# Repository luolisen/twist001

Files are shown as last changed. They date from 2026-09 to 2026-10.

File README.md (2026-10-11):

# twist001 · 六轴机械臂与具身智能实验

围绕自建六轴机械臂、双指夹爪和双相机开展建模、控制与具身智能实验。当前仓库以 **STM32 六轴固件、ESP32 夹爪固件、REV6 双相机 MuJoCo 仿真**为基础，保留三模型训练归档及机械设计资料。

本页更新至2026-10-10：固件与相机发布沿用2026-10-08记录，补入三模型阶段监督及v2技能研究结果。源码构建、仿真烟测、模型评估和实机验证分别记录，不将它们视为同一项验收。

## 当前模块

| 模块 | 仓库内容 | 状态与入口 |
| --- | --- | --- |
| STM32 六轴控制 | FinalIntegration v3.0，STM32F407VG，X42S CAN、示教/回放、夹爪链路 | 重新编译通过；[构建说明](arm/STM32/README.md) |
| ESP32 夹爪控制 | 配套纯 P 控制、端点减速、反向制动、CAN 节点 7、Wi-Fi/BLE 夹爪接口 | 重新编译通过；[配置与构建](arm/ESP32/README.md) |
| REV6 仿真 | 六轴机械臂、完整夹爪、前置与腕部相机、基础及方块任务场景 | 加载、渲染及短步数数值检查通过；[使用说明](model/RL/README.md) |
| 三模型与技能研究 | v1阶段监督、WM-FK、v2 Skill Router与Transport重力前馈 | 已知场景拿起保持、局部跟踪通过；完整搬运/放置未通过；[实验记录](model/three_model_training/README.md) |
| ROS 2 | 既有节点及已同步的 REV6 MuJoCo 资源 | 当前更新未进行 ROS 2 整链路验收；[集成边界](arm/README.md) |
| 机械资料 | SolidWorks、STEP、打印工程、材料清单及 PCB 资料 | 历史资料，尚未逐项核对与 REV6 的一致性；[机械资料说明](model/README.md) |

## 架构方向与集成状态

当前仿真架构采用**VLA阶段内连续生成动作、WM预测准备执行动作的后果、Jev发放有限且可撤销的阶段许可**。复合抓取抬升阶段覆盖夹爪接续及正常控制交还；每块持续检查公开输入、控制权和原物理保护。Jev拒绝、超时或无效返回不默认放行。

2026-10-10，同一次在线仿真完整执行34块/10880步，在10.880秒完成拿起保持；8.320秒原评价仍失败。完整物理轨迹与VLA加辅助成功基线一致，因此证明阶段监督保住了已知场景能力，尚未证明WM/Jev提升成功率、安全性或泛化。详见[实际结果与源码](model/three_model_training/experiments/skill_supervision_20261010/README.md)。

v2已实现Pick/Hold/Transport/Place/Recovery技能接口，局部固定结构重力前馈使末端跟踪误差由3.202mm降至0.196mm。最新长路径只取得70mm静态合法前缀，尚未物理执行；公开持物确认、自动Transport交接、Place松爪与完整抓放仍未通过。

```mermaid
flowchart TD
    Task[任务目标] --> Jev[Jev：阶段许可、拒绝与重规划]
    Obs[公开双相机、编码器与回执] --> VLA[SmolVLA：阶段内连续动作]
    Obs --> WM[World Model：未来响应与风险]
    VLA --> WM
    WM --> Jev
    Jev --> Gate[有限许可与控制所有权]
    VLA --> Gate
    Gate --> Protect[原限位、物理保护与执行回执]
    Protect --> Sim[已知MuJoCo场景拿起保持通过]
    Gate -. 技能交接仍待验证 .-> Skills[v2 Transport / Place]
    Protect -. 尚未联合验收 .-> STM[STM32六轴与ESP32夹爪]
```

本地 FinalIntegration 工程另有 `host/alan_robot` 主机控制层与独立 ROS 桥接包，**尚未纳入本仓库此次发布**。仓库中的既有 ROS 2 节点不能直接等同于这套新执行层。固件源码中已有配套 CAN 协议；新固件尚未烧录或完成实机联合验证。

## 快速开始：REV6 双相机仿真

从仓库根目录执行，使用独立 Python 环境：

```bash
python -m venv .venv
source .venv/bin/activate
python -m pip install -r model/RL/requirements.txt

# 基础机械臂与相机场景
python model/RL/src/demo.py

# 方块与放置目标场景
python model/RL/src/demo.py --scene task

# 离屏渲染两路图像并进行 100 步数值检查
python model/RL/src/demo.py --check /tmp/rev6-camera-check
```

上述环境激活命令适用于 macOS/Linux。macOS 打开交互窗口时，将 `python` 换为环境中的 `mjpython`；离屏检查使用普通 Python。

### 当前相机版本

| 相机 | 垂直视角 | 仿真原始图像 | 策略图像 | 处理方式 |
| --- | --- | --- | --- | --- |
| 前置 `front_rgb` | 48° | 640×360 | 256×256 | 完整视野缩为 256×144，上下各补 56 像素 |
| 腕部 `wrist_camera` | 45.2° | 640×360 | 512×512 | 完整视野缩为 512×288，上下各补 112 像素 |

该版本基于 REV6 Camera45.2，并加入实拍参考的前置相机姿态对齐。保留完整 16:9 视野，不以中心裁剪替代；逐设备内参、畸变与实机全运动可见性仍待验证。

模型来源、原始及发布文件指纹见 [provenance.json](model/RL/provenance.json)，相机合同见 [camera_contract.json](model/RL/camera_contract.json)。基础场景的桌板为视觉几何，任务场景的桌板有碰撞几何。旧独立 PPO 入口已被当前仿真包替换。

## 固件构建

### STM32F407VG

准备 ARM GNU 工具链和 CMake，在仓库根目录执行：

```bash
cmake -S arm/STM32/Control_Code -B /tmp/twist001-stm32-build \
  -DCMAKE_TOOLCHAIN_FILE="$PWD/arm/STM32/Control_Code/cmake/arm-gcc.cmake"
cmake --build /tmp/twist001-stm32-build -j4
```

工具链目录可通过 `STM32_ARM_TOOLCHAIN` 指定，详见 [STM32 文档](arm/STM32/README.md)。

### ESP32 夹爪

准备 Arduino CLI 和 esp32 core 3.3.11，在仓库根目录执行：

```bash
python3 arm/ESP32/tools/provision_wireless.py
arduino-cli compile --fqbn esp32:esp32:esp32doit-devkit-v1 \
  --build-property build.partitions=huge_app \
  --build-property upload.maximum_size=3145728 \
  --build-path /tmp/twist001-esp32-build arm/ESP32/ESP32_Final
```

配置工具为新环境生成本机密钥，并保留已有配置；私有配置不提交。固件使用 `huge_app` 3 MB 分区，无 OTA。以上命令只构建、不烧录，配置及客户端配套要求见 [ESP32 文档](arm/ESP32/README.md)。

## 已完成的验证与剩余工作

2026-10-08 的仓库更新验证包括：

- STM32 重新编译通过：FLASH 24,940 B、RAM 6,464 B。
- ESP32 重新编译通过：应用 1,710,674 B、全局 RAM 72,524 B，使用临时测试配置。
- 六组固件回归通过，覆盖协议、应用、CAN 分片、夹爪权限/租约及轨迹限速，并启用 ASan/UBSan。
- REV6 基础及任务场景在 MuJoCo 3.13.0 下通过加载、双相机渲染与各 100 步数值烟测。
- ROS MuJoCo 资源一致性及单项模型契约检查通过；未进行当前 ROS 工作空间的构建或运行验收。

可核对的记录见 [联合验证](arm/firmware_tools/verification.md) 和 [固件源码指纹](arm/firmware_tools/source_manifest.json)。这些固件与渲染检查不证明抓取、放置、碰撞或三模型任务成功率。WM19仍保留历史失败门槛；最新三模型闭环和局部控制结果单独归档，不追溯改写旧结果。

新固件烧录、六轴方向/传动比/参考位与限位标定、无线实机通信、相机校准、跨场景可靠性、完整抓放和实机模型闭环仍需分别完成。真实夹爪最大行程为 **74.63 mm**，仿真为 **80 mm**，模型动作接入时必须显式处理量程差异。

## 主要目录

以下仅列出当前工程入口及参考资料，不是仓库全部文件清单。

```text
twist001/
├── arm/
│   ├── STM32/Control_Code/       # 六轴与夹爪 CAN 链路固件
│   ├── ESP32/ESP32_Final/        # 配套夹爪固件
│   ├── ESP32/tools/              # 本机无线配置生成
│   ├── firmware_tools/          # 回归脚本、来源指纹与验证记录
│   └── ROS2/src/                # 既有 ROS 节点与 REV6 MuJoCo 资源
└── model/
    ├── RL/                      # REV6 场景、网格、渲染与相机合同
    ├── three_model_training/    # 三模型阶段监督、v2技能研究及WM19历史
    ├── 3D/                      # 历史机械设计与加工资料
    └── 机械臂材料清单.xlsx
```

仓库不提供训练权重、完整数据集、私有仿真状态、设备密钥或固件二进制。旧子目录说明中的历史路径与验证结论，应结合本页所述的当前集成范围使用。

## 许可证

仓库提供 [Apache License 2.0](LICENSE)。第三方驱动、SDK、模型和素材按各自附带的许可证或授权说明使用。

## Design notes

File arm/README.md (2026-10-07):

# 六轴与夹爪控制工程

当前主要入口是配套的 **STM32 六轴固件、ESP32 夹爪固件**及联合验证资料。

| 目录 | 内容 | 说明 |
| --- | --- | --- |
| [STM32](STM32/README.md) | FinalIntegration v3.0 六轴 CAN、示教/回放、夹爪链路 | STM32F407VG；重新编译通过 |
| [ESP32](ESP32/README.md) | 纯 P 夹爪控制、CAN 节点 7、Wi-Fi/BLE 接口 | 重新编译通过；无设备密钥及二进制 |
| [firmware_tools](firmware_tools/verification.md) | 六组回归、源码指纹及验证记录 | 软件验证，不等于实机验收 |
| [ROS2](ROS2/readme.md) | 既有 ROS 2 节点及资源 | 子目录说明包含历史配置，尚需适配当前执行链 |

## 控制分工

STM32 负责六轴电机控制以及与 ESP32 的夹爪 CAN 通信。ESP32 执行夹爪控制，并提供 Wi-Fi/BLE 夹爪查询和指令接口；当前并未实现 ESP32 脱离电脑转发六轴指令或直接连接手柄的 HID 驱动。

本地 FinalIntegration 的 `host/alan_robot` 和独立 ROS 桥接包尚未上传到此次仓库版本。它们负责模型量程适配、参考确认、标定/使能及动作时效门控等工作，不能用仓库现存的旧 ROS 节点代替其集成验收。

## 仿真与 ROS 2 边界

`ROS2/src/arm_asset/` 的 MuJoCo 资源已与 [REV6 双相机仿真](../model/RL/README.md)同步。前置相机为 48°，腕部为 45.2°。

- 当前 `mujoco_sim` 仍提供六关节控制与反馈话题，尚未接入夹爪控制和双相机图像话题。
- `arm_asset/urdf/` 是旧六轴描述，为原控制和标定模块保留；不是当前 REV6 完整夹爪和相机 URDF。
- 部分既有节点和启动文件仍使用旧路径、资源与接口配置。当前更新只完成静态资源和单项模型契约检查，未执行 ROS 2 整链路验证。

先运行仓库根目录说明中的独立仿真；ROS 接入需要另行核对模型、坐标、消息及执行网关。

## 硬件与验证状态

新固件未烧录，未进行最终版实机运动或联合闭环验收。六轴参考位、方向、传动比、限位及相机校准仍需独立验证。真实夹爪行程 0–74.63 mm，仿真为 0–80 mm，不能直接等同。

`STM32/` 下的 PCB 工程及原理图是保留的历史资料，本次没有核对其与 FinalIntegration 接线的一致性。最新软件检查结果见 [联合验证记录](firmware_tools/verification.md)。

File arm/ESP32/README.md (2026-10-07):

# ESP32 FinalIntegration v3.0 夹爪固件

配套 `arm/STM32/Control_Code/`。保留纯 P 控制、力矩保持、端点减速及反向制动；CAN 节点 7，另提供 Wi-Fi TCP 和 BLE GATT 夹爪接口，采用 HMAC、序号、租约、来源独占与有界队列。上电不自动张开。

硬件最大开口 **74.63 mm**，仿真为 **80 mm**，不能直接把两个量程混同。尚未完成无线实机及整臂闭环验收。ESP32 不提供无电脑的六轴 CAN 转发或手柄 HID 直连。

## 构建

安装 Arduino CLI 和 esp32 core 3.3.11。在仓库根目录生成本机独立配置；脚本保留已存在密钥，不打印密钥：

```sh
python3 arm/ESP32/tools/provision_wireless.py
arduino-cli compile --fqbn esp32:esp32:esp32doit-devkit-v1 --build-property build.partitions=huge_app --build-property upload.maximum_size=3145728 --build-path /tmp/twist001-esp32-build arm/ESP32/ESP32_Final
```

固件使用 esp32 core 提供的 Arduino、TWAI、Wire、Wi-Fi、BLE 与 mbedTLS 接口。配置在 `config/private/wireless.json`，生成的 `ESP32_Final/private_config.h` 不提交。配套客户端必须另行配置同一密钥；此次不发布原设备密钥或含密钥二进制。
使用 huge_app 3 MB 分区、无 OTA。此次只构建、不烧录；未来升级必须使用匹配分区表及启动文件。

本次 ESP32 发布源码与 FinalIntegration 原源文件逐字节相同，来源清单及联合验证见 `arm/firmware_tools/`。

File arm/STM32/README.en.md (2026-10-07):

# STM32 firmware

The current firmware is FinalIntegration v3.0 for STM32F407VG. See [current build and validation instructions](README.md). Historical PCB files are unchanged. No flashing or hardware validation was performed.

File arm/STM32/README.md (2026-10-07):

# STM32 FinalIntegration v3.0

当前 `Control_Code/` 全量替换为配套 ESP32 夹爪的 STM32F407VG 最终集成源码：六轴 X42S CAN 控制、示教/回放、有界同步命令、停止保持、夹爪 CAN 查询与控制。六轴回放期间允许夹爪链路，不自动归零。

在仓库根目录构建（只生成固件，不烧录）：

```sh
cmake -S arm/STM32/Control_Code -B /tmp/twist001-stm32-build -DCMAKE_TOOLCHAIN_FILE="$PWD/arm/STM32/Control_Code/cmake/arm-gcc.cmake"
cmake --build /tmp/twist001-stm32-build -j4
```

工具链可通过 `STM32_ARM_TOOLCHAIN` 指向包含 `bin/arm-none-eabi-gcc` 的目录。硬件为 STM32F407VG；链接脚本为 `STM32F407VG_FLASH.ld`。配套夹爪源码见 `arm/ESP32/`；联合回归见 `arm/firmware_tools/test_firmware.sh`。

当前源代码来自独立 FinalIntegration 工程，文件 SHA-256 见 `arm/firmware_tools/source_manifest.json`。`Control_Code/README.md` 与 `manifest.json` 是继承的原工程资料，路径和基线信息不代表当前发布验收；以本页和联合验证记录为准。
原 `jlc.epro2` 与 PCB/原理图图片原样保留，未在本次更新中核验硬件设计一致性。未烧录，未执行实机运动。完整主机网关与 ROS 桥接不在此次固件发布范围内。

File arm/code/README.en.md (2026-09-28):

# Local ASR and Qwen3.5 Testbed

**中文（默认）:** [README.md](README.md)

> **Module Maintainer**: [@LN-101](https://github.com/LN-101) (Responsible for AI CLI entrypoints, model benchmarks, voice/web launchers, and testing harness)

Run all commands from the repository root with `qwen35_env`:

```bash
./qwen35_env/bin/python Code/test.py --list-devices
./qwen35_env/bin/python Code/test.py inventory
./qwen35_env/bin/python Code/voice_stack.py plan
```

## Text Generation Smoke Tests

Qwen3.5 2B and 9B are detected as VLM-style OpenVINO GenAI models, so the
testbed uses `VLMPipeline` automatically.

```bash
./qwen35_env/bin/python Code/test.py generate \
  --model qwen35-2b \
  --device CPU \
  --prompt "Answer in one short sentence: what can you do for a robot safety assistant?" \
  --max-new-tokens 12

./qwen35_env/bin/python Code/test.py generate \
  --model qwen35-9b \
  --device CPU \
  --prompt "Answer in one short sentence: what is your role?" \
  --max-new-tokens 8
```

Device fallback is enabled by default when a requested accelerator fails:

```bash
./qwen35_env/bin/python Code/test.py generate --model qwen35-2b --device NPU --max-new-tokens 6
./qwen35_env/bin/python Code/test.py generate --model qwen35-2b --device GPU --max-new-tokens 6
```

For the current Qwen3.5 2B GPU tuning notes, use the benchmark harness below
with the target OpenVINO device and record the resulting `PerfMetrics` values.

The Qwen3.5 benchmark harness records official generated-token throughput,
TPOT, TTFT, stream chunk cadence, and a hardware telemetry snapshot:

```bash
./qwen35_env/bin/python Code/qwen35_benchmark.py --model qwen35-2b --device GPU
```

Use `official_tokens_per_second` / `mean_official_tokens_per_second` as the
model throughput metric. `stream_chunks_per_second` is only a streaming
smoothness diagnostic.

## ASR Smoke Tests

The Whisper path accepts normalized 16 kHz audio. The built-in WAV loader is
dependency-light and supports PCM WAV files only.

```bash
./qwen35_env/bin/python Code/test.py asr --load-only --device CPU --model whisper-large-v3-turbo
./qwen35_env/bin/python Code/test.py asr --device CPU --audio-sample /path/to/sample_16k.wav --language en
```

If no audio sample is provided, the ASR command validates the model path and
prints the required sample format.

## Safety Assistant Scaffold

The initial project scaffold validates local model assets and a JSON safety-rule
file. The rule store is intentionally owned by code, not by direct model file
writes.

```bash
./qwen35_env/bin/python Code/assistant.py status
```

The modular voice stack entrypoint is:

```bash
./qwen35_env/bin/python Code/voice_stack.py plan
./qwen35_env/bin/python Code/voice_stack.py text-turn --text "请说明机械臂急停规则" --skip-tts
./qwen35_env/bin/python Code/voice_stack.py audio-file --audio /path/to/sample_16k.wav --language zh --skip-tts
./qwen35_env/bin/python Code/voice_stack.py tts --text "机械臂已停止，请确认安全区域。"
```

The default TTS engine remains MeloTTS. A faster optional Piper Huayan backend
is available for listening tests; its default pause setting is the tuned
`--piper-silence-scale 1.0` candidate:

```bash
./qwen35_env/bin/python Code/voice_stack.py tts \
  --tts-engine piper \
  --piper-model-dir .trellis/tasks/05-28-compare-natural-chinese-tts-models/piper_speaches_huayan_model \
  --piper-espeak-data-dir .trellis/tasks/05-28-compare-natural-chinese-tts-models/sherpa_kokoro_model/kokoro-int8-multi-lang-v1_1/espeak-ng-data \
  --text "机械臂已停止，请保持安全距离，确认防护门关闭后再复位。"
```

The latest blind listening pack is under
`.trellis/tasks/05-28-compare-natural-chinese-tts-models/listening_eval/tuned_piper10_vs_melo/`.
Keep Piper optional until that pack wins the listening check. The current
rhasspy model card lists the HuaYan dataset URL as missing and the license as
unknown, so production use also needs an explicit license-risk acceptance or a
replacement voice with clear licensing.

ASR transcripts are normalized before routing. Install OpenCC in `qwen35_env`
so Traditional Chinese Whisper output is converted to Simplified Chinese before
rule/tool intent detection:

```bash
./qwen35_env/bin/python -m pip install opencc-python-reimplemented
```

No-wake realtime microphone listening uses an optional `sounddevice` runtime
dependency. It captures 16 kHz mono microphone audio, segments one utterance at
a time with an energy threshold, then runs the same ASR -> LLM -> ROS2 path:

```bash
sudo apt install portaudio19-dev
./qwen35_env/bin/python -m pip install sounddevice
./qwen35_env/bin/python Code/voice_stack.py listen --no-wake --language zh --skip-tts --dry-run-ros2
```

Useful tuning options are `--speech-threshold`, `--trailing-silence-seconds`,
`--min-speech-seconds`, `--max-utterance-seconds`, `--mic-device`, and
`--max-turns`. Use `--no-ros2` when you only want local ASR/Qwen output during
microphone tuning.

The ROS2 bridge commands run the same voice turn and publish ROS2 topic
messages. Use `--dry-run-ros2` first to inspect the planned messages without
requiring `rclpy`:

```bash
./qwen35_env/bin/python Code/voice_stack.py ros2-text-turn --text "请立即急停机械臂" --skip-tts --dry-run-ros2
./qwen35_env/bin/python Code/voice_stack.py ros2-audio-file --audio /path/to/sample_16k.wav --language zh --skip-tts --dry-run-ros2
```

## Mobile Web UI

The hotspot web surface is a separate entrypoint:

```bash
./qwen35_env/bin/python Code/web_ui.py
```

For the HTTPS phone UI launcher:

```bash
./scripts/start_web_no_ros.sh
```

For real ROS2 Web debugging, build/source the ROS2 workspace, start the default
arm launch, and start the Web UI without `--dry-run-ros2` through:

```bash
./scripts/start_web_with_ros.sh
```

The default launch is `ros2 launch main arm.launch.py`; its default real-robot
path does not start MuJoCo simulation or the K230 camera node. Override the
target with `--ros-launch-package <pkg>` and `--ros-launch-file <file>` or the
matching `AI_OV_ROS2_LAUNCH_PACKAGE` / `AI_OV_ROS2_LAUNCH_FILE` environment
variables. Use `--skip-ros-build` when the ROS2 workspace is already built.
The default build runs plain `colcon build` inside the ROS2 workspace and lets
the ROS build/launch processes inherit that workspace's Python dependency
resolution; it does not force `--symlink-install` or prepend system
`dist-packages`.

Both Web launchers keep Web/ASR at effective nice `0` by default, and the MOSS
TTS child inherits that priority. Set `AI_OV_VOICE_NICE` to an unprivileged
value from `0` through `19` to override it. Vision inference runs at nice `10`
by default; set `AI_OV_MIN_DIS_NICE` in the same range to override it. Negative,
invalid, or unattainable values fail before Web or ROS processes start. The
real ROS launcher leaves arm control, arm state, and emergency-stop aggregation
at nice `0`; only `min_dis` is demoted.

MOSS streaming playback buffers `0.48` seconds of PCM before it starts. After
an underrun it waits for `0.64` seconds of PCM before resuming, giving playback
a larger fixed recovery reserve while retaining the low initial latency now
that YOLO no longer competes for the CPU. Set
`AI_OV_MOSS_PCM_BUFFER_SECONDS=2`, `3`, or `4` to opt back into a larger initial
reserve when comparing latency and continuity under contention.
The default Web stream sends `voice=Xiaoyu` without a prompt WAV, so the ONNX
runtime uses its built-in prompt codes and avoids encoding `zh_11.wav` for each
turn. An explicit `--moss-prompt-audio <wav>` or
`--moss-use-yangmi-prompt-audio` setting still selects reference-audio cloning.
Starting a new Web text or voice turn now stops local playback and waits for the
previous backend/MOSS stream to cancel before the new request begins. The ONNX
worker keeps exclusive ownership of the shared runtime until it exits and its
codec streaming state is reset. If cancellation logs `runtime restart
required` or `/health` reports `runtime_manager.runtime_healthy=false`, restart
the MOSS/Web launcher instead of retrying concurrent turns in the same server.
MOSS affinity is disabled by default; use
`AI_OV_MOSS_CPUS=<cpu-list>` only for explicit affinity experiments. These
settings do not change Web,
ASR, arm control, emergency-stop, or the existing `min_dis` E-core affinity.

If another terminal already owns the full ROS2 graph, attach only the Web UI
without starting duplicate arm/camera nodes:

```bash
./scripts/start_web_with_ros.sh --no-ros-launch
```

The real ROS launcher rejects `--dry-run-ros2`; use `scripts/start_web_no_ros.sh` for
safe UI-only testing.

Before starting the Orbbec/Gemini vision snapshot service as a normal user,
install the udev rules shipped with the ROS2 environment's `pyorbbecsdk`.
Gemini 336 enumerates as `2bc5:0803`; without this rule it can appear in
`lsusb` while the Orbbec SDK still fails with `Access denied` /
`usbEnumerator openUsbDevice failed`:

```bash
sudo sh "$AI_OV_ROS2_WORKSPACE/.venv/lib/python3.12/site-packages/pyorbbecsdk/shared/install_udev_rules.sh"
```

After installing the rule, unplug and replug the camera before starting the
vision service.

To also build and start the ROS2 RGB snapshot service used by visual-analysis
requests:

```bash
./scripts/start_web_no_ros.sh --with-vision-service
```

The launcher still passes `--dry-run-ros2` to the Web UI by default, so robot
command publishing remains disabled while `/vision/capture_snapshot` is
available for VLM snapshots. The service is provided by the ROS2 `camera`
package's `min_dis` node, which also owns the Orbbec RGB/depth pipeline and
minimum-distance context. Use `--vision-service-name <name>` or
`--vision-output-dir <dir>` to override the `min_dis` vision parameters. Use
`--vision-show-window` only when the OpenCV preview windows are wanted.

Do not use `--with-vision-service` if a full ROS2 launch such as
`ros2 launch main arm.launch.py` is already running `min_dis`; two
camera nodes can compete for the same Orbbec device.

It serves a mobile-first local UI with `admin / 12345` login by default,
text chat, browser voice upload, playback of generated TTS audio, and an
emergency-stop button. The first MVP intentionally excludes image upload and
full autonomous arm-agent control.

For real ROS2 publishing, source ROS2 and the workspace first. By default,
emergency-stop voice commands publish JSON requests to `/safety/estop/request`;
use `--direct-estop-topic` only when publishing `std_msgs/Bool` directly to
`/emergency_stop` is desired. The same emergency-stop and release commands also
write the configured arm runtime JSON (`--arm-rules`, default
`Code/config/arm_rules.json`) by setting `arm_stop` / `arm_recover`.

When the Web UI runs without `--dry-run-ros2`, it also subscribes to
`/safety/estop/request` and turns active external stop events (for example the
visual person-distance stop published by the `min_dis` node with
`source=min_distance_camera`) into a browser emergency alert: pending Web work
is canceled, an emergency popup shows the source/reason/distance/threshold, and
a pre-generated alert audio file is played directly with a browser `Audio`
element (never realtime TTS). Provide the audio file at
`local_safety_assistant/web/assets/emergency_alert.wav` with the fixed message
`警告！检测到不安全情况，已经急停`, or replace it with
`--emergency-alert-audio <path>`; it is served at `/emergency-alert-audio`.
The `min_dis` stop is latched after its first unsafe distance. Safe or missing
detections do not release it automatically. A confirmed release asks the camera
to reset, but the camera clears only after either three consecutive valid frames
at least `0.05m` above the configured stop distance or five seconds of valid
camera frames with no person detected. Person reappearance, camera frame loss,
or stale evidence cancels the no-person eligibility; otherwise the stop remains
active.
Synthetic events can be injected through the authenticated
`POST /api/estop/external` route using the same multi-source JSON contract
(`source`, `active`, `latch`, `reason`, plus optional `distance_m`,
`trigger_distance_m`, `threshold_m`, and `release_distance_m`). Camera alerts
show the first unsafe trigger distance, latest person-to-arm distance, and
release gate separately. Dismissing the popup never releases the real emergency stop;
release remains owned by the ROS2 stop-source logic.

The example rule file is:

```text
Code/config/safety_rules.example.json
```

Current-rule questions such as `当前安全规则是什么` are read through the
validated rule tool path, not from prompt memory. Each voice turn first asks
the 2B model for a bounded JSON route: final spoken reply, `load_rules`, or
`edit_rules`. The legacy keyword detector is only a fallback when the route is
invalid. The model may request rule reads with a structured JSON tool envelope
such as `{"type":"tool_call","name":"load_rules","arguments":{}}`; the legacy
`TOOL:load_rules` marker remains a fallback. The default example now
covers personnel intrusion, unknown objects, guard doors, light curtains, ROS
controller alarms, and teach-mode speed limits. After the JSON document is
loaded, Qwen is prompted to understand the rule fields and answer in natural
Chinese: broad questions should summarize every enabled rule briefly without
appending a follow-up suggestion tail, while specific questions should explain only the
matching JSON rule. `Code/voice_stack.py` and `Code/batch_voice_safety.py` both
default to this file and accept `--rules` to point at another validated JSON
rule document.

Rule-edit turns no longer construct a default 9B rule editor. The router should
select `edit_rules` for natural edit requests such as `调整人员安全距离到 1.2 米`;
the patch stage then produces a constrained patch against an existing rule, and
project code applies that patch through validated atomic writes. The checked-in
runtime default is `two-pass` while the MVP is being compared; use
`--rule-edit-strategy one-pass` or `--rule-edit-strategy two-pass` on
`Code/voice_stack.py text-turn --skip-tts` to compare both patch-generation
paths before choosing long-term policy.

Explicit vision requests such as `调用视觉，分析下当前工作环境` route through a
bounded `analyze_environment_vision` tool. The assistant calls a configurable
ROS2 `std_srvs/Trigger` snapshot service, defaulting to
`/vision/capture_snapshot`; on success the Trigger `message` must be JSON with
an `image_path` field and optional `stamp` / `frame_id` metadata:

```json
{"image_path": "/tmp/current_rgb_snapshot.jpg", "stamp": "2026-06-09T12:00:00", "frame_id": "camera_color"}
```

The first implementation is RGB-only. The assistant validates and copies the
snapshot into the authenticated Web runtime image directory, runs Qwen3.5 VLM
analysis, returns a concise Chinese safety summary, and renders the captured
image in the Web chat message. Depth metadata and colorized depth images are
reserved for a later iteration.

If the RGB camera is already published as `sensor_msgs/Image`, the included
snapshot provider node can expose that Trigger service:

```bash
source /opt/ros/<distro>/setup.bash
./qwen35_env/bin/python Code/vision_snapshot_node.py \
  --image-topic /camera/color/image_raw \
  --service-name /vision/capture_snapshot
```

The node accepts common RGB image encodings (`rgb8`, `bgr8`, `rgba8`, `bgra8`,
and `mono8`) and writes JPEG snapshots under `.runtime/vision_snapshots/`.

## Optional Downloads

The testbed is offline once model directories exist. Use the downloader only
to fetch or refresh model assets:

```bash
./qwen35_env/bin/python Code/download.py qwen35-2b
./qwen35_env/bin/python Code/download.py qwen35-9b
./qwen35_env/bin/python Code/download.py asr-whisper-large-v3
./qwen35_env/bin/python Code/download.py asr-whisper-large-v3-turbo
```

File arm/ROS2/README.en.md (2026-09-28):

# ROS 2 Arm Workspace

**中文（默认）:** [readme.md](readme.md)

This directory is the authoritative ROS 2 workspace for the integrated
`nl-industrial-arm-safety` monorepo. It contains the packages that connect the
natural-language AI layer to the camera, arm controller, simulation, and
operator GUI.

> **Module Maintainer**: [@nanshanbot](https://github.com/nanshanbot) (Responsible for ROS 2 node architecture, arm kinematics control, camera RGB-D distance safety & vision snapshots, multi-source e-stop arbitration, MuJoCo simulation & PyQt5 GUI)

## Packages

| Package | Responsibility |
| --- | --- |
| `camera` | Orbbec RGB/depth input, person/arm distance estimation, camera emergency-stop source, and vision snapshot Trigger service |
| `control` | IK, DRL, hand-eye calibration, and control helpers |
| `main` | Launch files, arm state machine, serial feedback, and emergency-stop aggregation |
| `arm_asset` | URDF/MJCF robot description and meshes |
| `mujoco_sim` | MuJoCo simulation node |
| `arm_gui` | PyQt5 ROS 2 status and manual stop interface |

## Build

From the monorepo root:

```bash
source /opt/ros/jazzy/setup.bash
cd ros2
colcon build
source install/setup.bash
```

Generated `build/`, `install/`, `log/`, and `.runtime/` directories are local
state and are intentionally ignored.

## Launch

The integrated launcher normally starts the default arm path from the
repository root:

```bash
./scripts/start_web_with_ros.sh
```

To launch the ROS graph directly:

```bash
source /opt/ros/jazzy/setup.bash
source /path/to/nl-industrial-arm-safety/ros2/install/setup.bash
ros2 launch main arm.launch.py
```

The default real-robot launch does not start MuJoCo simulation or the K230
camera node. Inspect the launch files before selecting simulation or hardware
paths on a new machine.

```bash
ros2 topic pub /goal geometry_msgs/msg/Point "{x: 0.08, y: 0.25, z: 0.2}" --once
```

## Vision Context Snapshot

`camera.min_dis` exposes an AI_ov-compatible Trigger service while keeping the
existing minimum-distance topics unchanged.

Run the camera node:

```bash
source /opt/ros/<distro>/setup.bash
source /path/to/nl-industrial-arm-safety/ros2/install/setup.bash
ros2 run camera min_dis --ros-args \
  -p vision_service_name:=/vision/capture_snapshot \
  -p vision_output_dir:=/path/to/nl-industrial-arm-safety/ros2/.runtime/vision_snapshots
```

Call the service:

```bash
ros2 service call /vision/capture_snapshot std_srvs/srv/Trigger {}
```

On success, `message` is JSON with:

```json
{
  "image_path": "/path/to/nl-industrial-arm-safety/ros2/.runtime/vision_snapshots/vision_context_123.jpg",
  "stamp": "2026-07-05T10:00:00.000Z",
  "frame_id": "camera_frame",
  "min_distance_m": 0.42,
  "human_closest_point": {"x": 0.1, "y": 0.2, "z": 0.7},
  "arm_closest_point": {"x": 0.3, "y": 0.2, "z": 0.6},
  "emergency_stop": false,
  "fresh": true,
  "age_ms": 12.3,
  "source": "min_dis"
}
```

If no completed frame analysis is available, or the cached frame/context is
older than `vision_max_age_ms` (default `1000`), the service returns
`success=false` with a short human-readable error. The image extension parameter
accepts `jpg`, `jpeg`, or `png`.

Use Git branches or patches for team handoff. Do not copy a zip over this
workspace; stage teammate code elsewhere, review the diff, then merge selected
changes.

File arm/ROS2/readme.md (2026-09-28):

# `ros2/` ROS 2 工作空间

**English:** [README.en.md](README.en.md)

这是 `nl-industrial-arm-safety` 的权威 ROS 2 工作空间，负责把自然语言安全助手连接到相机、机械臂控制器、仿真器和操作员 GUI。构建产物 `build/`、`install/`、`log/` 和 `.runtime/` 只在本机生成，不提交到 Git。

> **模块维护者**：[@nanshanbot](https://github.com/nanshanbot)（负责 ROS 2 节点架构、机械臂运动学控制、相机 RGB-D 距离安全与视觉快照、多来源急停仲裁、MuJoCo 仿真及 PyQt5 GUI）

## 包结构

| 包 | 主要文件/节点 | 职责 |
| --- | --- | --- |
| `camera` | `camera/min_dis.py`、`distance_estop.py`、`pose_distance.py` | Orbbec RGB-D、YOLO/OpenVINO 人体/机械臂距离、相机急停和视觉上下文 |
| `control` | `control/ik_control.py`、`drl_control.py` | 逆运动学、DRL 策略、关节控制和手眼参数读取 |
| `main` | `launch/*.launch.py`、`main/arm_state.py` | 启动图、串口协议、工作空间边界、抓放状态机和安全规则同步 |
| `main` | `main/estop_aggregator.py` | 聚合语音、相机、反馈和手动急停来源 |
| `arm_asset` | `urdf/`、`mjcf/`、`meshes/` | 机械臂模型、碰撞/视觉网格和 MuJoCo 资源 |
| `mujoco_sim` | `mujoco_sim/mujoco_sim.py` | `/goal`、`/control`、手眼控制和关节状态的 MuJoCo 仿真 |
| `arm_gui` | `arm_gui/gui_node.py`、`main_window.py` | 状态显示、目标/关节命令和手动急停界面 |

## 关键文件

```text
ros2/
├── colcon_defaults.yaml       colcon 默认构建选项
├── src/
│   ├── arm_asset/             URDF、MJCF、STL 网格和展示图片
│   ├── camera/                相机、距离安全和视觉快照
│   ├── control/               IK、DRL、手眼和策略资源
│   ├── main/                  真实机械臂启动图、状态机和急停仲裁
│   ├── mujoco_sim/            仿真节点和仿真测试
│   └── arm_gui/               PyQt5 ROS 2 GUI
└── readme.md                  本中文说明
```

相机包中随源码保留的二进制 SDK/模型资源可能有独立许可证，重新分发前必须核查来源和条款。

## 构建

在仓库根目录执行：

```bash
source /opt/ros/jazzy/setup.bash
cd ros2
colcon build
source install/setup.bash
```

如果使用外部 ROS 2 工作空间，根目录启动脚本支持：

```bash
AI_OV_ROS2_WORKSPACE=/path/to/ros2 ./scripts/start_web_with_ros.sh
```

默认启动脚本会优先使用仓库内的 `./ros2`，并在真实启动前拒绝存在未提交的 ROS 2 源码/配置变更。仅在明确的本地实验中使用 `AI_OV_ALLOW_DIRTY_ROS=1`。

## 启动图

### 默认真实机械臂路径

```bash
source /opt/ros/jazzy/setup.bash
source install/setup.bash
ros2 launch main arm.launch.py
```

根目录的完整入口会先构建/加载工作空间，再启动 Web UI：

```bash
cd ..
./scripts/start_web_with_ros.sh
```

`main/launch/arm.launch.py` 默认连接：

```text
control/ik_control
        |
main/arm_state -------- main/estop_aggregator
        |
camera/min_dis -------- /emergency_stop
```

默认图不会自动启动 MuJoCo 或 K230 节点。真实硬件启动前，应先审查 launch 参数、串口设备、模型路径、相机状态和急停链路。

### 其他 launch 文件

| 文件 | 用途 |
| --- | --- |
| `arm.launch.py` | 默认控制、状态、相机和急停图 |
| `arm_ik_real.launch.py` | 更直接的真实机械臂 IK 路径 |
| `arm_ik_sim.launch.py` | IK + MuJoCo 仿真路径 |
| `arm_drl_sim.launch.py` | DRL 控制 + MuJoCo 仿真路径 |
| `handeye_calibration.launch.py` | 手眼标定维护图，默认不启用运动 |

仿真/标定都不是生产真实机械臂默认路径。请先阅读对应 launch 文件和节点参数，再在目标设备执行。

## 主要 ROS 2 接口

| 接口 | 类型 | 发布/订阅方 | 作用 |
| --- | --- | --- | --- |
| `/goal` | `geometry_msgs/Point` | AI 桥接、GUI、`arm_state`/仿真 | 目标笛卡尔坐标 |
| `/control` | `sensor_msgs/JointState` | 控制器、GUI、仿真 | 六关节控制目标 |
| `/robot_joint_state` | `sensor_msgs/JointState` | `arm_state` | 真实机械臂反馈 |
| `/mujoco_joint_state` | `sensor_msgs/JointState` | `mujoco_sim`、GUI | 仿真关节反馈 |
| `/min_distance` | `std_msgs/Float32` | `camera/min_dis`、GUI | 人/臂最小距离 |
| `/safety/estop/request` | `std_msgs/String` | 语音/相机、`estop_aggregator` | 带来源和原因的急停请求 JSON |
| `/emergency_stop` | `std_msgs/Bool` | 急停聚合器、控制器、GUI | 有效急停状态 |
| `/voice/transcript` | `std_msgs/String` | AI 桥接 | 语音转写文本 |
| `/voice/assistant_response` | `std_msgs/String` | AI 桥接 | 助手回答 |
| `/vision/capture_snapshot` | `std_srvs/srv/Trigger` | `camera/min_dis` | 获取带时间戳的视觉快照上下文 |

视觉快照调用示例：

```bash
ros2 service call /vision/capture_snapshot std_srvs/srv/Trigger '{}'
```

服务成功时，`message` 为 JSON，包含图片路径、时间戳、帧 ID、最小距离、最近点、急停状态、帧新鲜度和来源。

## 相机安全节点

`camera/min_dis.py` 负责：

- 读取 Orbbec RGB-D 数据；
- 使用 YOLO/OpenVINO 姿态模型识别人和机械臂关键点；
- 在深度无效时使用受限的历史/候选恢复策略；
- 发布 `/min_distance` 和视觉上下文；
- 通过 `/safety/estop/request` 请求锁存相机急停。

默认启动图会把视觉推理限制到指定 CPU、线程数和 `nice`/CPUWeight 范围，以避免语音播放被视觉推理饿死。相机故障、帧过期或距离未知不能被解释为“工作空间安全”。

## 控制与急停

`control/ik_control.py` 从 URDF 读取运动链，进行目标姿态/工作空间/关节限制检查，并将关节目标交给控制接口。`main/arm_state.py` 负责串口反馈、抓放状态机、工作空间边界和控制器通信；它还会拒绝过期、越界或急停状态下的命令。

`main/estop_aggregator.py` 将多个来源合并为一个有效状态：

```json
{"source":"voice_assistant","active":true,"latch":true,"reason":"用户请求急停"}
```

只允许对应来源按规则释放锁存；清除某一个来源不能覆盖其他仍然激活的来源。物理急停和下位机安全链路仍然是最终保护措施。

## 仿真与 GUI

MuJoCo 节点加载 `arm_asset/mjcf/arm_mjcf.xml`，订阅 `/goal` 和 `/control`，发布 `/mujoco_joint_state`，并对关节目标做速度限制。GUI 节点提供目标点、六关节控制、状态订阅和手动 `/emergency_stop`。

这些路径需要桌面显示、MuJoCo/PyQt5 和完整 ROS 2 Python 依赖：

```bash
source /opt/ros/jazzy/setup.bash
source install/setup.bash
ros2 launch main arm_ik_sim.launch.py
```

## 测试

```bash
source /opt/ros/jazzy/setup.bash
cd ros2
colcon test --event-handlers console_direct+
```

当前工作空间可以成功 `colcon build`。`colcon test` 中仍有既存的风格/文档检查失败和少量机械臂状态标定/时序断言差异；这些结果不代表真实硬件安全验收。

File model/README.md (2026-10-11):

# 机械设计与 REV6 仿真

当前独立仿真入口是 [REV6 双相机仿真](RL/README.md)，包括完整夹爪、腕部相机、前置相机以及任务场景。旧 PPO 脚本及独立仿真目录中的旧 URDF 已从当前版本替换；历史内容仍可从 Git 历史查看。

- [仿真启动、依赖及相机合同](RL/README.md)
- [模型来源与文件指纹](RL/provenance.json)
- [三模型阶段监督与技能研究](three_model_training/README.md)
- [历史机械设计资料](3D/) 与 [材料清单](机械臂材料清单.xlsx)：本次未更新，不代表已与 REV6 一致。

相机是实拍对齐候选，完整光学校准与实机运动验证未完成。模型加载及渲染验证不代表任务成功率或碰撞安全验收。

2026-10-10研究记录已补入：已知场景拿起保持及局部重力前馈跟踪通过；完整Transport/Place、公开自主交接和实机仍未通过。源码与精简证据见[研究归档](three_model_training/experiments/skill_supervision_20261010/README.md)。

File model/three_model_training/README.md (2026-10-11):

# 三模型监督、技能研究与历史训练记录

当前仿真分工是VLA负责阶段内连续动作，WM负责动作条件化的未来响应与风险预测，Jev负责有界阶段许可、拒绝、异常处理与重规划。阶段授权通过真实执行门生效，原物理保护独立优先。

- [2026-10-10阶段监督与v2技能研究](experiments/skill_supervision_20261010/README.md)：已知场景10.880秒拿起保持通过，8.320秒未通过；局部Transport前馈跟踪通过，长路径只到静态检查阶段。
- [WM19八候选训练历史](experiments/wm19/README.md)：保留原训练与完整性结果，其独立物理可靠性门槛仍未通过。

当前没有完整三色分拣、自动抓放、公开自主持物确认、实机或实时闭环通过证据。v1与原动作辅助基线轨迹相同，不据此宣称监督收益。v2确定性Transport/Place仍需独立交接、路径、支撑与释放验证，不加载未验证的新Place模型冒充能力。

本目录发布源码快照、精简记录和静态名义指令；不提供神经权重、完整训练集、私有integration_state、设备密钥或固件二进制。离线复核入口不运行模型或物理。研究运行器仍依赖原登记资产与显式有限授权，不能由归档状态自动启动实机。

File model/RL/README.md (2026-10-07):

# REV6 双相机仿真

当前版本完整替换旧独立仿真目录，包含 REV6 机械臂、联动双指夹爪、腕部相机及对齐后的前置相机。
默认 `src/model/mjcf/arm_mjcf.xml` 是相机对齐场景；`task_scene.xml` 是同相机版本的方块与放置目标任务场景。

| 相机 | 视角 | 原始渲染 | 策略图像 | 内容与补边 |
| --- | --- | --- | --- | --- |
| front_rgb | 48° | 640×360 | 256×256 | 256×144，上下各 56 |
| wrist_camera | 45.2° | 640×360 | 512×512 | 512×288，上下各 112 |

保持完整 16:9 视野，不用中心裁剪。前置相机世界位置为 (0.3665, 0.029, 0.355) m；机械臂绕 (0.08, 0.08, 0) 旋转 −90°。相机姿态来自实拍人工对齐，尚未完成逐设备内参、畸变及全运动可见性验收。

## 使用

在仓库根目录安装依赖并运行：

```sh
python -m pip install -r model/RL/requirements.txt
python model/RL/src/demo.py
python model/RL/src/demo.py --scene task
python model/RL/src/demo.py --check /tmp/rev6-camera-check
```

macOS 打开交互窗口使用环境中的 `mjpython model/RL/src/demo.py`。离屏检查使用普通 Python。
仿真启动姿态 J1–J6 为 [0, −0.05, 0.1, 0, 0, 0] rad；控制接口为六个关节目标加夹爪开度（米，0–0.08）。这不是实机上电零位。

## 来源和验证边界

基体来源 `ARM_REV6_CAMERA45P2_MUJOCO`，SHA-256 为 `49cc167d19aba3cf02702e98f1f95e64fabc3dab05aa267ec67d476d4028c7eb`。
相机对齐场景源 SHA-256 为 `986230eea6327b3e1f6a4b470eb44d1582c53c0ac463c3670da4547319da9bc8`；任务场景源为 `02defa53b8d934771f32aed1d0b767bd1a6a820715d5fc0a7eaffa46189cf9ce`。
打包仅修改资源相对路径及 XML 序列化；几何、相机和动力学没有改动，发布文件的新 hash 见 `provenance.json`。

旧六轴 PPO 的 arm.py/test.py 与旧 URDF 副本不纳入本目录；它们不适配当前夹爪、相机和任务接口。三模型历史训练记录保留在 `model/three_model_training/`。
本目录不含数据集、训练权重或自动训练入口。模型加载、图像渲染及短步数烟测不等于抓取成功、碰撞验收、策略可靠性或实机验证。默认对齐场景的桌板是视觉几何；任务场景的桌板有碰撞几何。未合入静态碰撞修复候选。

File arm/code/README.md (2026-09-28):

# `Code/` 命令入口与测试

**English:** [README.en.md](README.en.md)

`Code/` 是仓库根目录下的开发者入口层。这里的 Python 文件大多是兼容性包装器、模型测试命令或批处理工具；核心安全逻辑位于 [`local_safety_assistant/`](../local_safety_assistant/)。

> **模块维护者**：[@LN-101](https://github.com/LN-101)（负责 AI 兼容入口、模型评测、语音与 Web 启动脚本及测试工具链）

## 文件职责

| 路径 | 作用 |
| --- | --- |
| `test.py` | 设备、模型、文本生成和 ASR 冒烟测试入口，实际调用 `local_safety_assistant.model_testbed` |
| `voice_stack.py` | 语音栈 CLI 入口，实际调用 `local_safety_assistant.stack.cli` |
| `web_ui.py` | 移动端 Web UI 入口，实际调用 `local_safety_assistant.web.server` |
| `download.py` | 从 Hugging Face 下载模型到被忽略的 `models/` |
| `piper_tts.py` | Piper TTS 的外部运行器适配 |
| `qwen35_benchmark.py` | Qwen/OpenVINO 生成吞吐和设备遥测基准 |
| `asr_benchmark.py` | Whisper ASR 性能测试辅助 |
| `batch_voice_safety.py` | 批量语音安全回归任务 |
| `assistant.py` | 早期本地助手兼容入口 |
| `vision_snapshot_node.py` | 视觉快照兼容入口；ROS 2 集成实现位于 `ros2/src/camera/` |
| `config/` | 安全规则、机械臂规则和对象标号映射示例 |
| `runtime/` | 不含凭据的运行时配置样例 |
| `tests/` | Python 单元测试和启动脚本契约测试 |

不要直接从模型输出写入 `Code/config/`。规则和对象映射必须通过核心包中的校验与确认流程更新。

## 环境

从仓库根目录执行命令。项目默认使用 `qwen35_env`，也可以把下面命令中的解释器替换成自己的 Python 3.12 环境。

```bash
PY=./qwen35_env/bin/python
$PY -m unittest discover -s Code/tests
$PY -m py_compile Code/*.py local_safety_assistant/stack/*.py local_safety_assistant/web/*.py
```

模型、虚拟环境、缓存和运行时输出不在 Git 中。模型下载前请阅读模型卡和许可证。

## 设备与模型检查

```bash
$PY Code/test.py --list-devices
$PY Code/test.py inventory
$PY Code/voice_stack.py plan
$PY Code/voice_stack.py audio-devices
```

`plan` 输出 ASR、LLM、视觉和 TTS 的 OpenVINO 设备选择；没有对应模型或硬件时，检查命令会明确报告缺失状态。

下载模型到被忽略的 `models/` 目录：

```bash
$PY Code/download.py qwen35-2b
$PY Code/download.py asr-whisper-large-v3-turbo
```

可用别名以 `Code/download.py --help` 和源码中的 `MODEL_REPOS` 为准。需要 Hugging Face 权限时，在本机设置 `HF_TOKEN`，不要把令牌写入命令历史或仓库。

## 文字、音频和语音栈

### 文字回合

先使用 dry-run，确认不会发布真实 ROS 2 命令：

```bash
$PY Code/voice_stack.py text-turn \
  --text "请说明机械臂急停规则" \
  --skip-tts \
  --dry-run-ros2
```

常用参数包括 `--llm-model`、`--asr-model`、`--rules`、`--object-mapping`、`--arm-rules` 和 `--max-new-tokens`。

### 音频文件

输入必须是可读取的 PCM WAV，推荐单声道、16 kHz：

```bash
$PY Code/voice_stack.py audio-file \
  --audio /path/to/sample_16k.wav \
  --language zh \
  --skip-tts \
  --dry-run-ros2
```

### 麦克风

```bash
$PY Code/voice_stack.py listen \
  --language zh \
  --max-turns 1 \
  --no-ros2
```

调试麦克风时先使用 `--no-ros2`；`--speech-threshold`、`--trailing-silence-seconds`、`--mic-device` 和 `--max-utterance-seconds` 用于调整端点检测。

### TTS

```bash
$PY Code/voice_stack.py tts \
  --text "机械臂已进入安全状态" \
  --tts-engine melo
```

支持 `moss`、`melo` 和 `piper` 三种适配器。运行时、模型和厂商/第三方依赖需要在本机单独安装；本仓库不提供一键安装脚本。

## ROS 2 桥接

语音栈默认只生成计划；启用 ROS 2 桥接后，完成的回合会按确定性规则发布：

```bash
$PY Code/voice_stack.py ros2-text-turn \
  --text "请立即急停机械臂" \
  --skip-tts \
  --dry-run-ros2
```

去掉 `--dry-run-ros2` 才会尝试连接 ROS 2。桥接使用的默认话题为：

| 话题 | 类型 | 用途 |
| --- | --- | --- |
| `/voice/transcript` | `std_msgs/String` | 规范化后的输入文本 |
| `/voice/assistant_response` | `std_msgs/String` | 助手回答 |
| `/safety/estop/request` | `std_msgs/String` | 带来源和原因的急停请求 |
| `/emergency_stop` | `std_msgs/Bool` | 直接急停状态 |
| `/goal` | `geometry_msgs/Point` | 经过解析的目标坐标 |

规则查询、规则编辑、对象映射和抓取意图不会被当成普通坐标命令直接发布；它们必须经过对应的确认/解析流程。

## Web UI

从仓库根目录使用启动脚本：

```bash
./scripts/start_web_no_ros.sh
```

这个模式默认使用 `--dry-run-ros2`，适合界面、ASR、LLM 和 TTS 联调。完整 ROS 2 集成使用：

```bash
./scripts/start_web_with_ros.sh
```

详细环境变量包括 `AI_OV_PYTHON`、`AI_OV_WEB_HOST`、`AI_OV_WEB_PORT`、`AI_OV_WEB_ADMIN_PASSWORD`、`AI_OV_TTS_ENGINE` 和 `AI_OV_ROS2_WORKSPACE`。Web 默认凭据只适合本地开发，部署前必须更改。

## 配置文件

- `config/safety_rules.example.json`：规则文档示例，包含版本、规则条件和动作；
- `config/arm_rules.json`：机械臂急停、恢复、减速等运行时规则；
- `config/object_mapping.example.json`：A/B/C/D 对象标号示例；
- `runtime/voice_stack.example.json`：不含秘密的语音栈参数样例。

修改规则时，核心包会检查 JSON 类型、重复 ID、已知业务字段、距离范围和不可修改字段，并使用临时文件加原子替换写回。

## 测试范围

```bash
$PY -m unittest discover -s Code/tests
$PY -m py_compile Code/*.py local_safety_assistant/stack/*.py local_safety_assistant/web/*.py scripts/*.py
bash -n scripts/start_web_no_ros.sh scripts/start_web_with_ros.sh
```

测试不代表真实机械臂安全认证。涉及 ROS 2、相机、串口、模型和 TTS 的集成行为必须在目标设备上另外验收。

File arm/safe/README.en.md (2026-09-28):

# `local_safety_assistant/` Local Safety Assistant Core

**中文（默认）:** [README.md](README.md)

This is the project's core Python package. It integrates local ASR, LLM/VLM, TTS, vision context, and the Web UI, while strictly bounding model outputs within verifiable rules, confirmation lifecycles, and deterministic ROS 2 message boundaries.

> **Module Maintainer**: [@LN-101](https://github.com/LN-101) (Responsible for AI core architecture, OpenVINO inference, Whisper/MeloTTS speech pipeline, safety rule engine, Web UI, and ROS 2 message bridge)

## Processing Pipeline

```text
Text / Audio Input
    |
    +--> stack/asr.py -------- Whisper ASR
    |
    +--> stack/pipeline.py --- Intent normalization, rule tools, LLM response
    |          |
    |          +-------------- rules.py / arm_rules.py
    |          +-------------- object_mapping.py
    |          +-------------- workspace_snapshot.py
    |
    +--> stack/tts.py -------- Melo / MOSS / Piper TTS
    |
    +--> stack/ros2_bridge.py  Deterministic ROS 2 message plan or publish
    |
    +--> web/service.py ------ Web session, confirmations, emergency stop, streaming audio
```

## Files and Modules

| Path | Responsibility |
| --- | --- |
| `app.py` | `status` command; checks OpenVINO devices, models, TTS runtimes, and rule files |
| `config.py` | Project root discovery, model aliases, and default asset paths |
| `rules.py` | Loading, schema & business validation, preview generation, and atomic writing of safety rule JSON |
| `arm_rules.py` | Robot arm E-stop, reset, slowdown requests, and runtime rule synchronization |
| `object_mapping.py` | Reading, validating, and updating A/B/C/D object-to-label mappings |
| `confirmation.py` | Confirmation state machine and lifecycle management for high-risk operations |
| `workspace_snapshot.py` | Aggregating rules, object mappings, arm status, and pending confirmations into workspace snapshots |
| `model_testbed.py` | OpenVINO model discovery, device inspection, and text/ASR generation smoke tests |
| `stack/asr.py` | Whisper OpenVINO ASR integration and transcription normalization |
| `stack/llm.py` | Qwen/OpenVINO text/VLM inference adapter |
| `stack/pipeline.py` | Single-turn interaction, tool routing, response synthesis, and action intent orchestration |
| `stack/tts.py` | Unified TTS interface supporting MeloTTS, MOSS, and Piper |
| `stack/devices.py` | CPU/GPU/NPU hardware probing and stage-wise device selection |
| `stack/microphone.py` | Microphone audio capture, voice activity/endpoint detection, and WAV input |
| `stack/vision.py` | ROS 2 Trigger vision snapshot parsing, path verification, and caching |
| `stack/vision_node.py` | Standalone ROS 2 camera snapshot Trigger node |
| `stack/ros2_bridge.py` | Deterministic translation of confirmed voice/text intents into ROS 2 message plans |
| `stack/safety_batch.py` | Batch voice safety regression test runner |
| `web/server.py` | HTTP/HTTPS server, authentication, routing, and static asset serving |
| `web/service.py` | Web service business state, confirmation flows, E-stop, chat session, and audio streaming |
| `web/ui.py` | Mobile-first control dashboard HTML/JS generation |
| `web/assets/` | E-stop alert sounds and localized text assets |

## Entry Commands

Run all commands from the repository root:

```bash
PY=./qwen35_env/bin/python

# Check model inventory and device allocation plan
$PY -m local_safety_assistant.app status
$PY Code/voice_stack.py plan

# Text turn without speech synthesis or live ROS 2 publishing
$PY Code/voice_stack.py text-turn \
  --text "Please explain the robotic arm emergency stop rules" \
  --skip-tts \
  --dry-run-ros2

# Launch Web server (prefer root launcher scripts during development)
$PY Code/web_ui.py --help
./scripts/start_web_no_ros.sh
```

`Code/voice_stack.py` and `Code/web_ui.py` are compatibility wrappers; the underlying CLI implementations reside in `stack/cli.py` and `web/server.py`.

## Safety Boundaries

### Rules and Mappings

The model is strictly restricted to proposing tool calls or rule patches and cannot write directly to JSON files. `rules.py` enforces:

- Document versioning, rule arrays, and unique IDs;
- Strict data types for `enabled`, conditions, and actions;
- Immutable identity fields and action types;
- Numerical range limits on human distance thresholds;
- Safe writing via temporary files, `fsync`, and atomic replacement (`os.replace`).

Object mappings undergo equivalent structural validation. All operations that alter safety rules or configurations must pass through the `confirmation.py` confirmation workflow.

### ROS 2 Message Planning

`stack/ros2_bridge.py` first generates an inspectable `Ros2MessagePlan`. Default topics include:

| Topic | Type | Description |
| --- | --- | --- |
| `/voice/transcript` | `std_msgs/String` | Recognized input text |
| `/voice/assistant_response` | `std_msgs/String` | Assistant text response |
| `/safety/estop/request` | `std_msgs/String` | E-stop request with source, latch flag, and reason |
| `/emergency_stop` | `std_msgs/Bool` | Direct emergency stop state |
| `/goal` | `geometry_msgs/Point` | Coordinate goal point |

Explanations, rule edits, object mappings, and grasp intents never bypass the tool layer to publish directly to `/goal`. Use `--dry-run-ros2` during development and testing to inspect message plans without real hardware interaction.

### Web Sessions

`web/service.py` manages authenticated sessions, pending confirmations, chat turn cancellation, external E-stops, and audio/image streaming. Default credentials (`admin` / `12345`) are intended for local development only; production deployments require updating passwords, restricting network interfaces, and configuring TLS.

## Configuration Sources

Default configuration is resolved via `stack/config.py`:

- ASR: `models/asr/whisper-large-v3-turbo-int4-ov`
- LLM: `models/Qwen3.5-2B-int4-ov`
- Rules: `Code/config/safety_rules.example.json`
- Object Mapping: `Code/config/object_mapping.example.json`
- Arm Rules: `Code/config/arm_rules.json`
- Vision Snapshot Service: `/vision/capture_snapshot`

Model weights, TTS runtimes, and virtual environments are not tracked in Git. When models are absent, status checks will explicitly report missing assets; do not commit large binary model files.

## Testing

```bash
./qwen35_env/bin/python -m unittest discover -s Code/tests
./qwen35_env/bin/python -m py_compile \
  local_safety_assistant/stack/*.py \
  local_safety_assistant/web/*.py
```

The test suite covers rule validation, confirmation lifecycles, ASR/TTS adapters, vision snapshot parsing, Web APIs, voice stack, and ROS 2 message planning. Passing unit tests does not substitute for hardware-in-the-loop safety acceptance on the physical robot arm.

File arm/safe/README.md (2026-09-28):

# `local_safety_assistant/` 本地安全助手核心

**English:** [README.en.md](README.en.md)

这是项目的 Python 核心包。它把本地 ASR、LLM、TTS、视觉上下文和 Web UI 连接起来，同时把模型输出限制在可校验的规则、确认和 ROS 2 消息边界内。

> **模块维护者**：[@LN-101](https://github.com/LN-101)（负责 AI 核心架构、OpenVINO 推理、Whisper/MeloTTS 语音链路、规则校验引擎、Web UI 与 ROS 2 桥接层）

## 处理链路

```text
文字/音频输入
    |
    +--> stack/asr.py -------- Whisper ASR
    |
    +--> stack/pipeline.py --- 意图归一化、规则工具、LLM 回答
    |          |
    |          +-------------- rules.py / arm_rules.py
    |          +-------------- object_mapping.py
    |          +-------------- workspace_snapshot.py
    |
    +--> stack/tts.py -------- Melo/MOSS/Piper TTS
    |
    +--> stack/ros2_bridge.py 确定性 ROS 2 计划或发布
    |
    +--> web/service.py ------ Web 会话、确认、急停和流式音频
```

## 文件和模块

| 路径 | 职责 |
| --- | --- |
| `app.py` | `status` 命令，检查 OpenVINO 设备、模型、TTS 和规则文件 |
| `config.py` | 项目根目录、模型别名和默认模型路径 |
| `rules.py` | 安全规则 JSON 的加载、业务校验、预览和原子写入 |
| `arm_rules.py` | 机械臂急停、恢复、减速请求及运行时规则同步 |
| `object_mapping.py` | A/B/C/D 对象映射的读取、校验和更新 |
| `confirmation.py` | 高风险动作的确认状态和生命周期 |
| `workspace_snapshot.py` | 将规则、对象映射、机械臂状态和待确认操作汇总为快照 |
| `model_testbed.py` | OpenVINO 模型发现、设备检查和生成测试 |
| `stack/asr.py` | Whisper OpenVINO ASR 和识别结果标准化 |
| `stack/llm.py` | Qwen/OpenVINO 文本/VLM 推理适配 |
| `stack/pipeline.py` | 单轮输入、工具调用、回答和动作意图编排 |
| `stack/tts.py` | Melo、MOSS、Piper 的统一 TTS 接口 |
| `stack/devices.py` | CPU/GPU/NPU 设备探测和阶段级设备选择 |
| `stack/microphone.py` | 麦克风采集、端点检测和 WAV 输入 |
| `stack/vision.py` | ROS 2 Trigger 视觉快照的解析、路径校验和缓存 |
| `stack/vision_node.py` | 可独立启动的视觉快照 Trigger 节点 |
| `stack/ros2_bridge.py` | 将已确认的语音结果转换为 ROS 2 消息计划 |
| `stack/safety_batch.py` | 批量安全语音回归执行 |
| `web/server.py` | HTTP/HTTPS 服务、认证、路由和静态响应 |
| `web/service.py` | Web 业务状态、确认、急停、聊天和音频流 |
| `web/ui.py` | 移动端控制页面 HTML |
| `web/assets/` | 急停提示音及其文本资源 |

## 入口命令

从仓库根目录运行：

```bash
PY=./qwen35_env/bin/python

# 检查模型和设备计划
$PY -m local_safety_assistant.app status
$PY Code/voice_stack.py plan

# 文字回合，不合成语音，不发布真实 ROS 2 命令
$PY Code/voice_stack.py text-turn \
  --text "请说明机械臂急停规则" \
  --skip-tts \
  --dry-run-ros2

# 启动 Web 服务（开发时优先使用根目录启动脚本）
$PY Code/web_ui.py --help
./scripts/start_web_no_ros.sh
```

`Code/voice_stack.py` 和 `Code/web_ui.py` 是兼容入口，实际解析器分别位于 `stack/cli.py` 和 `web/server.py`。

## 安全边界

### 规则和映射

模型只能提出工具调用或规则补丁，不能直接写入 JSON。`rules.py` 会检查：

- 文档版本、规则数组和唯一 ID；
- `enabled`、条件和动作的数据类型；
- 不允许修改的身份字段和动作类型；
- 人员距离阈值的数值范围；
- 临时文件写入、`fsync` 和原子替换。

对象映射同样需要结构校验。所有需要改变安全状态或配置的操作都必须进入 `confirmation.py` 的确认流程。

### ROS 2 消息计划

`stack/ros2_bridge.py` 先生成可检查的 `Ros2MessagePlan`，默认话题包括：

| 话题 | 类型 | 说明 |
| --- | --- | --- |
| `/voice/transcript` | `std_msgs/String` | 输入文本 |
| `/voice/assistant_response` | `std_msgs/String` | 助手回答 |
| `/safety/estop/request` | `std_msgs/String` | 带来源、锁存和原因的急停请求 |
| `/emergency_stop` | `std_msgs/Bool` | 直接急停状态 |
| `/goal` | `geometry_msgs/Point` | 坐标目标 |

文字解释、规则编辑、对象映射和抓取意图不会绕过工具层直接变成 `/goal`。开发和测试时使用 `--dry-run-ros2` 查看计划。

### Web 会话

`web/service.py` 管理登录会话、待确认操作、聊天回合取消、外部急停和音频/图像输出。默认 Web 凭据只适合本地开发；生产部署必须更改密码、限制网络接口并启用合适的 TLS 与访问边界。

## 配置来源

默认配置在 `stack/config.py`：

- ASR：`models/asr/whisper-large-v3-turbo-int4-ov`；
- LLM：`models/Qwen3.5-2B-int4-ov`；
- 规则：`Code/config/safety_rules.example.json`；
- 对象映射：`Code/config/object_mapping.example.json`；
- 机械臂规则：`Code/config/arm_rules.json`；
- 视觉快照服务：`/vision/capture_snapshot`。

模型权重、TTS 运行时和 Python 环境不随仓库提供。缺失模型时，状态检查会报告缺失，不应通过提交大文件来绕过环境配置。

## 测试

```bash
./qwen35_env/bin/python -m unittest discover -s Code/tests
./qwen35_env/bin/python -m py_compile \
  local_safety_assistant/stack/*.py \
  local_safety_assistant/web/*.py
```

测试覆盖规则校验、确认状态、ASR/TTS 适配、视觉快照解析、Web API、语音栈和 ROS 2 消息计划。通过单元测试不等于目标机械臂安全验收。

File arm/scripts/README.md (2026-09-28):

# 项目脚本与启动工具 (`scripts/`)

本目录集中存放系统的运行启动脚本、进程与资源调度辅助库，以及独立的路由/规则测试工具。

> **维护者**：[@LN-101](https://github.com/LN-101)（负责系统级启动脚本、cgroup 资源调度与集成测试工具）

---

## 脚本概览

| 脚本文件 | 类型 | 职责说明 |
| --- | --- | --- |
| [`start_web_no_ros.sh`](start_web_no_ros.sh) | Shell 脚本 | **Web / 语音 dry-run 启动脚本**。启动移动端 Web UI，默认开启 `--dry-run-ros2`（不发布真实机械臂硬件命令），支持可选拉起 Orbbec 相机视觉快照服务。 |
| [`start_web_with_ros.sh`](start_web_with_ros.sh) | Shell 脚本 | **Web + ROS 2 完整图启动脚本**。自动构建并加载 ROS 2 工作空间，启动 `main/launch/arm.launch.py`（含 IK 控制、人体距离检测、多来源急停仲裁）以及 Web 交互界面。 |
| [`launcher_nice.sh`](launcher_nice.sh) | Shell 库 | **进程调度与资源分配辅助库**。由启动脚本 `source` 引入，负责校验 nice 优先级、cgroup v2 `CPUWeight`、CPU 核心亲和性绑定（taskset）及 systemd 用户会话支持。 |
| [`test_rule_query_routing.py`](test_rule_query_routing.py) | Python 脚本 | **规则查询与意图路由测试脚本**。独立验证自然语言规则查询识别（`should_read_rules`）、路由器 Prompt 关键指令构建以及意图分发覆盖率。 |

---

## 脚本详细说明

### 1. `start_web_no_ros.sh`（Dry-Run 启动）

适用于算法调试、Web UI 界面联调、ASR 语音识别、LLM 对话逻辑及 MeloTTS/Piper 语音合成测试，无需连接真实机械臂硬件。

#### 运行方式

从项目根目录执行：

```bash
./scripts/start_web_no_ros.sh
```

#### 常用参数

- `--with-vision-service`：构建并拉起 ROS 2 相机快照服务（用于视觉大模型图像上下文抓取）；
- `--skip-vision-build`：跳过 ROS 2 `camera` 包的构建直接启动视觉服务；
- `--vision-service-name <name>`：指定 ROS 2 Trigger 视觉快照服务名（默认 `/vision/capture_snapshot`）；
- `--vision-output-dir <dir>`：指定快照保存目录（默认 `$ROS2_WORKSPACE/.runtime/vision_snapshots`）；
- `--vision-show-window`：显示 `min_dis` OpenCV 图像预览窗口；
- 其他参数透传给 [`Code/web_ui.py`](../Code/web_ui.py)。

---

### 2. `start_web_with_ros.sh`（完整 ROS 2 图启动）

适用于连接真实机械臂或完整 ROS 2 节点图运行。该脚本会执行工作空间干净度检查，启动底层控制节点，并拉起具备真实 ROS 2 命令发布能力的 Web UI。

#### 运行方式

从项目根目录执行：

```bash
./scripts/start_web_with_ros.sh
```

#### 常用参数

- `--with-ros-launch`：启动默认机械臂 ROS 2 Launch 图（默认行为）；
- `--no-ros-launch`：仅启动 Web UI 并连接到已由其他终端运行的 ROS 2 图（避免重复拉起节点）；
- `--skip-ros-build`：跳过 `colcon build` 直接启动；
- `--no-min-dis-window`：后台运行 `min_dis` 距离检测但隐藏 OpenCV 预览窗口；
- `--ros-launch-package <pkg>`：指定 Launch 包（默认 `main`）；
- `--ros-launch-file <file>`：指定 Launch 文件（默认 `arm.launch.py`）。

> [!IMPORTANT]
> 为确保操作安全，该脚本在启动前会检查 ROS 2 工作空间是否存在未提交的代码变更。若在本地调试中确需临时运行未提交代码，可设置环境变量 `AI_OV_ALLOW_DIRTY_ROS=1`。

---

### 3. `launcher_nice.sh`（资源与调度校验库）

由 `start_web_no_ros.sh` 与 `start_web_with_ros.sh` 自动引入，主要功能包括：

- **优先级约束**：校验 `AI_OV_VOICE_NICE` 与 `AI_OV_MIN_DIS_NICE`（范围 0~19），确保非特权用户无法非法提权；
- **cgroup v2 CPU 权重分配**：通过 `systemd-run --user --scope` 隔离语音进程组（默认权重 500）与视觉推理进程（默认权重 25），避免 YOLO 视觉推理抢占 P-Core 算力导致 TTS 语音卡顿；
- **核心亲和性校验**：校验 `taskset -c` 格式（如 `4-6` 将视觉绑定至 E-Core）；
- **环境预检**：检查 systemd 用户会话是否已激活 `cpu` 控制器。

---

### 4. `test_rule_query_routing.py`（规则路由验证）

用于快速检验自然语言意图分类器对“安全规则查询”句式的识别准确性。

#### 运行方式

从项目根目录执行：

```bash
python scripts/test_rule_query_routing.py
```

#### 校验内容

1. **Python 函数识别**：验证 `should_read_rules()` 对 20 余种常见及边缘安全规则问法（如“当前安全规则是什么”、“有哪些规则”、“防护门规则是什么”等）的判定；
2. **Prompt 构建检查**：验证 `build_agent_router_prompt()` 是否正确注入 `load_rules` 指令与示例；
3. **集成链路检查**：验证规则查询端到端路由配置一致性。

---

## 常用环境变量

| 环境变量 | 默认值 | 作用说明 |
| --- | --- | --- |
| `AI_OV_PYTHON` | `./qwen35_env/bin/python` | 主 Python 解释器路径 |
| `AI_OV_WEB_HOST` | `0.0.0.0` | Web 服务监听地址 |
| `AI_OV_WEB_PORT` | `8787` | Web 服务端口 |
| `AI_OV_WEB_ADMIN_USERNAME` | `admin` | Web 登录用户名 |
| `AI_OV_WEB_ADMIN_PASSWORD` | `12345` | Web 登录密码（生产环境务必修改） |
| `AI_OV_TTS_ENGINE` | `auto` | TTS 引擎选择（`auto` / `melo` / `piper`） |
| `AI_OV_ROS2_WORKSPACE` | `./ros2` | ROS 2 工作空间根目录 |
| `AI_OV_ROS2_SETUP` | `/opt/ros/jazzy/setup.bash` | ROS 2 系统环境变量脚本 |
| `AI_OV_VOICE_CPU_WEIGHT` | `500` | Web / 语音进程的 cgroup CPUWeight |
| `AI_OV_MIN_DIS_CPU_WEIGHT` | `25` | 视觉距离检测进程的 cgroup CPUWeight |
| `AI_OV_MIN_DIS_CPUS` | `4-6` | 视觉检测绑定的 CPU 核心编号 |

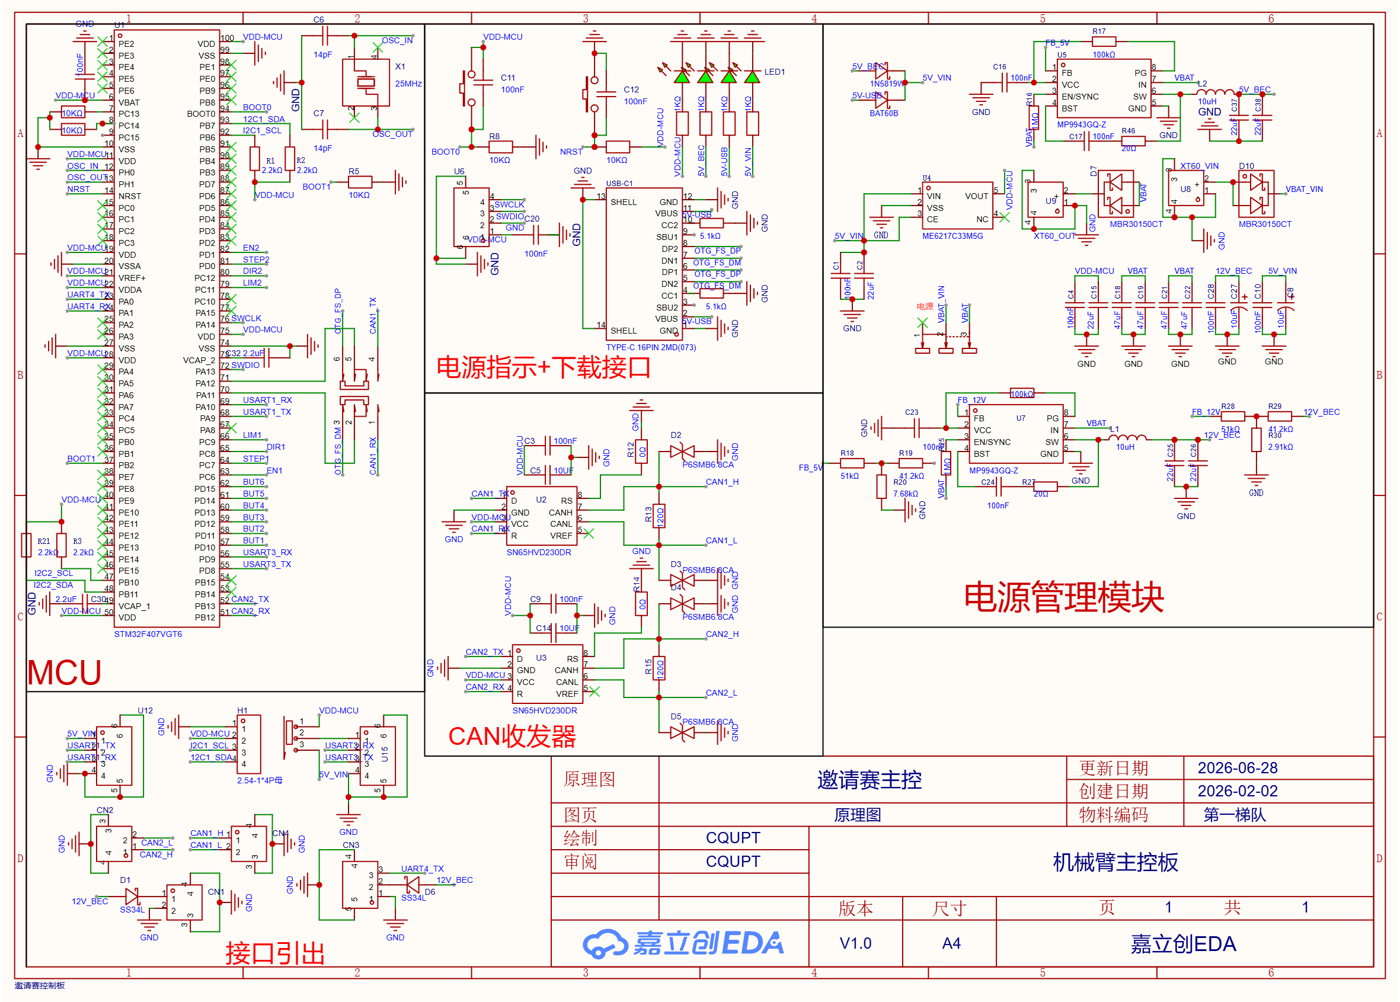
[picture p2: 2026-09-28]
arm/STM32/SCH_2026-06-28.png

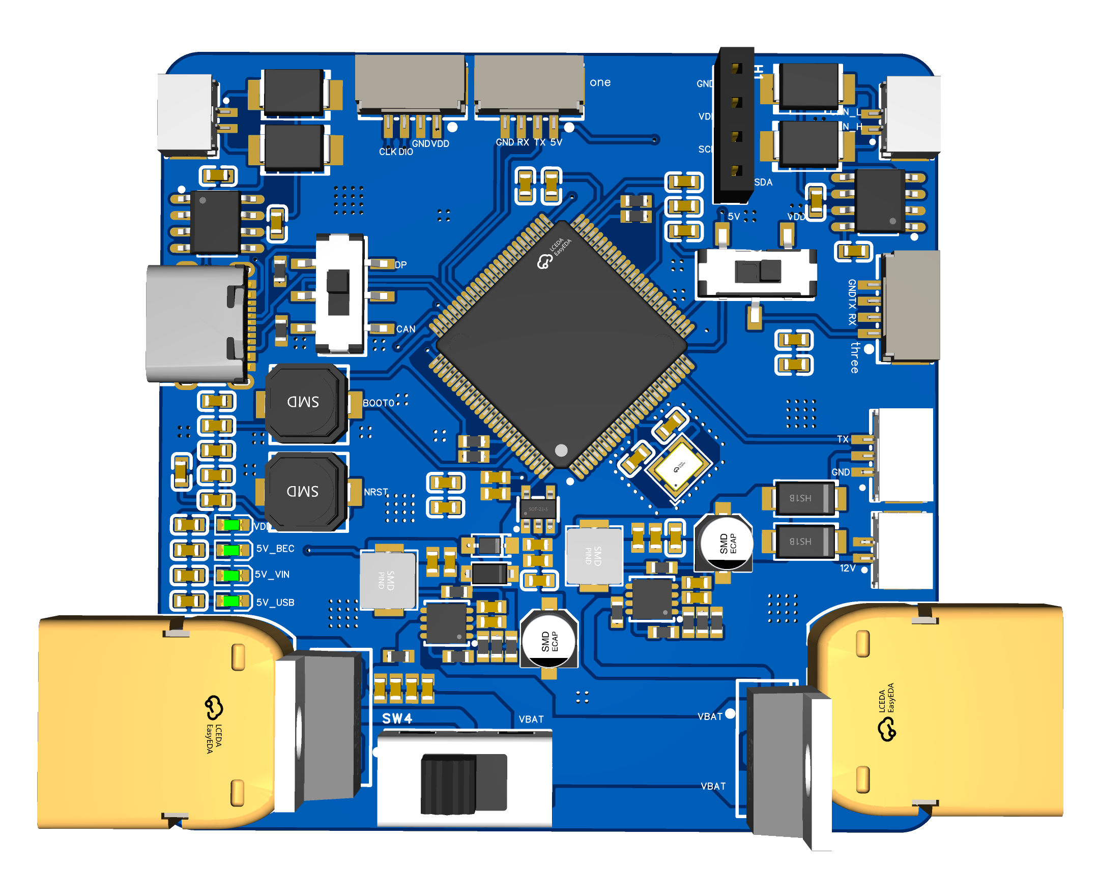
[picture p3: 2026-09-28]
arm/STM32/3D_PCB1_2026-06-28.png

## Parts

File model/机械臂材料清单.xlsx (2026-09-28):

 | 机械臂 整体材料清单
序号 | 子件品名 | 封装 | 数量 | 单位 | 链接 | 备注 | 总价
1 | 42步进电机 | 正点原子或张大头任意42电机都可 | 6 | 个 |  |  | 480
2 | 42减速器 | 减速比30 | 3 | 个 | 【淘宝】假一赔四 https://e.tb.cn/h.8pqKXaYYPo42EU3?tk=GlEZTgKoz20 HU006 「高精密行星减速机配步进电机42/57/86减速器齿轮箱圆法兰方法兰」 点击链接直接打开 或者 淘宝搜索直接打开 |  | 312
3 | 42减速器 | 减速比10 | 2 | 个 | 【淘宝】假一赔四 https://e.tb.cn/h.8pqKXaYYPo42EU3?tk=GlEZTgKoz20 HU006 「高精密行星减速机配步进电机42/57/86减速器齿轮箱圆法兰方法兰」 点击链接直接打开 或者 淘宝搜索直接打开 |  | 154
4 | 联轴器 | 单模 外径26长26内孔5至10 | 3 | 个 | 【淘宝】7天无理由退货 https://e.tb.cn/h.8MaON1jz112gwMS?tk=aGy1TgKs00w CZ028 「膜片联轴器铝合金 可开键槽可变径连接器高精度丝杆连轴器编码器」 点击链接直接打开 或者 淘宝搜索直接打开 | 将减速器尺寸图发给商家，开槽。内孔选8，然后这个连轴器我是一个将它拆成两个，用于减速器轴和1其他件的连接 | 66
5 | 同步带 | 宽度10mm HTD3M180*齿数60 | 1 | 个 | 【淘宝】7天无理由退货 https://e.tb.cn/h.8MaKZef5E2Ynj7U?tk=hcRGTgKEdOt HU293 「同步带3M108-288/291/294/297/300/303/306/309/312/315/318-558」 点击链接直接打开 或者 淘宝搜索直接打开 |  | 5
6 | 同步轮 | BF 3M30齿 11宽 孔5 圆孔 | 2 | 个 | 【淘宝】7天无理由退货 https://e.tb.cn/h.8LVkKyNSX8v0D8P?tk=8NdLTgKBnEM tG-#22>lD 「同步轮HTD3M30齿30T槽宽11/16齿外径27.8 凸台带顶丝同步带轮BF型」 点击链接直接打开 或者 淘宝搜索直接打开 |  | 14
7 | 圆轴 | Φ5*40 | 1 | 个 | 【淘宝】假一赔四 https://e.tb.cn/h.8pqAxqFeHb0I1pK?tk=WoHeTgqZZlU CA381 「304不锈钢圆柱销 定位销固定销轴实心销子销钉M2M3M4M5M6M8M10M12」 点击链接直接打开 或者 淘宝搜索直接打开 |  | 1
8 | cnc加工件 |  |  |  |  | 铨洲或者嘉立创cnc加工都可以 | 50
9 | 3d打印件 |  |  |  |  |  | 20
 |  |  |  |  |  |  | 1102 | 这个价格是估算的，仅供参考

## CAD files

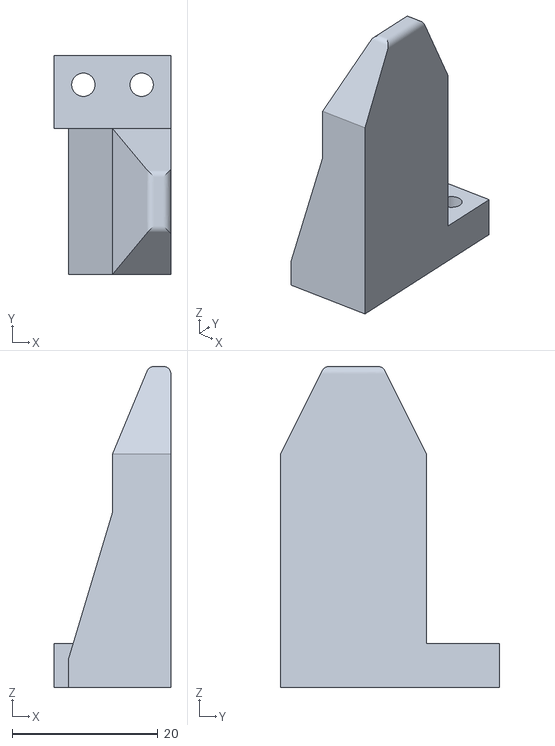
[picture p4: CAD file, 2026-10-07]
arm/ROS2/src/arm_asset/meshes/Left_Finger.stl
16.0 x 30.0 x 44.0

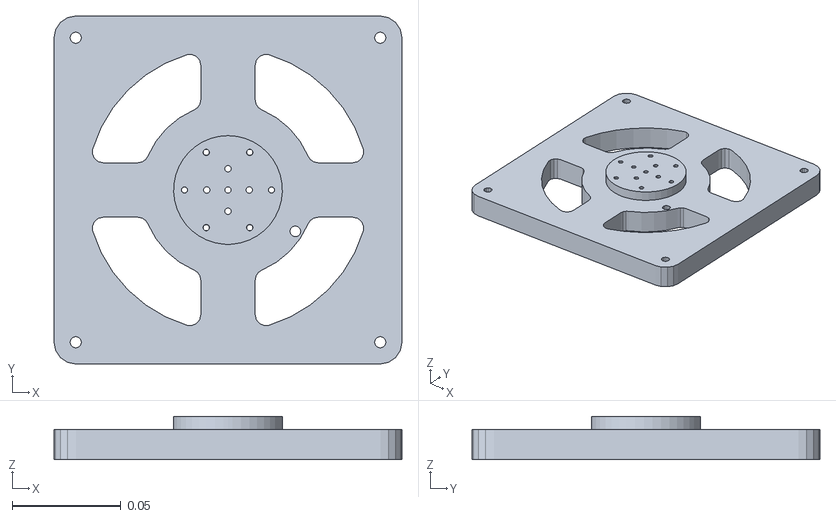
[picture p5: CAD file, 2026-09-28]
arm/ROS2/src/arm_asset/urdf/base_link.STL
0.16 x 0.16 x 0.02

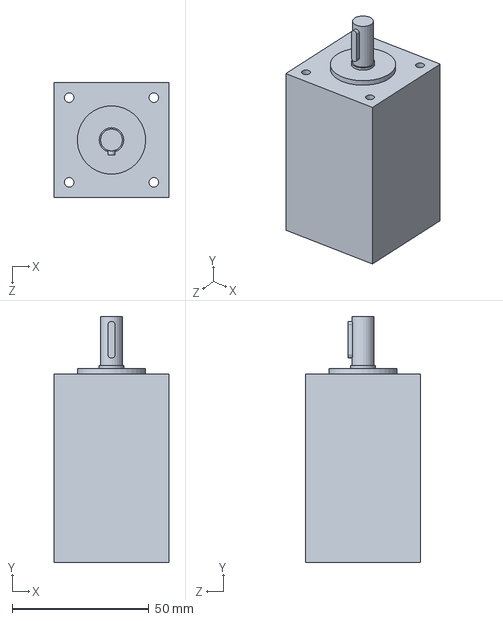
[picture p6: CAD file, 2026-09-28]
model/3D/sw/减速比30减速器.SLDPRT
42.0 x 90.0 x 42.0 mm

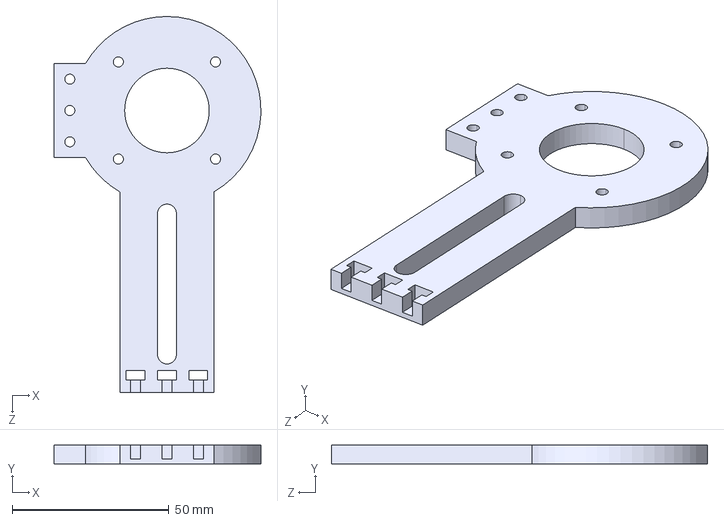
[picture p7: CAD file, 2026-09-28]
model/3D/加工/cnc/j1_2.STEP
66.0 x 6.00 x 120.0 mm

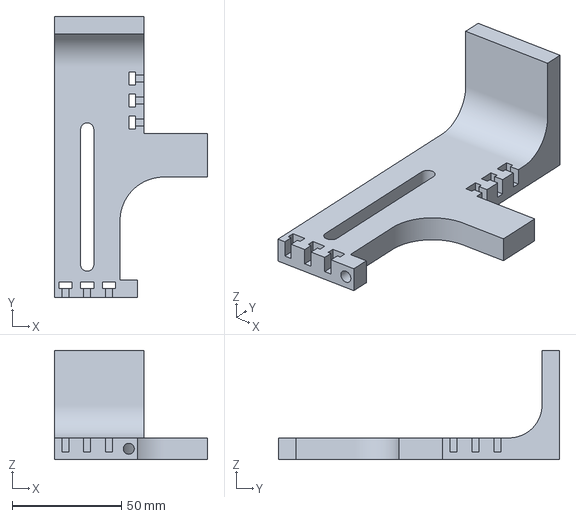
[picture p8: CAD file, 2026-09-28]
model/3D/加工/打印件/j1_3_PETGCF_P1S.3mf
70.0 x 128.4 x 50.0 mm

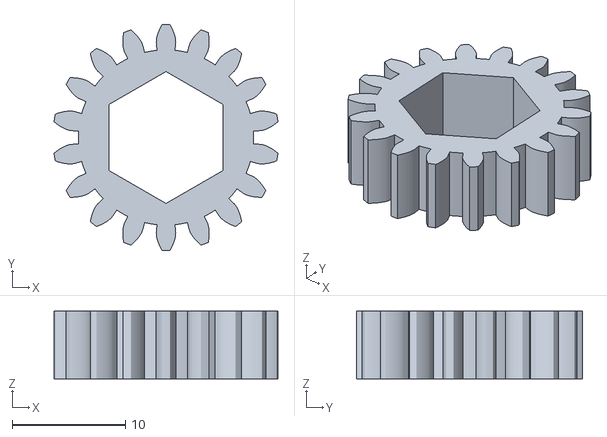
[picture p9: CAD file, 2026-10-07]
model/RL/src/model/meshes/Pinion.stl
19.8 x 20.0 x 6.00

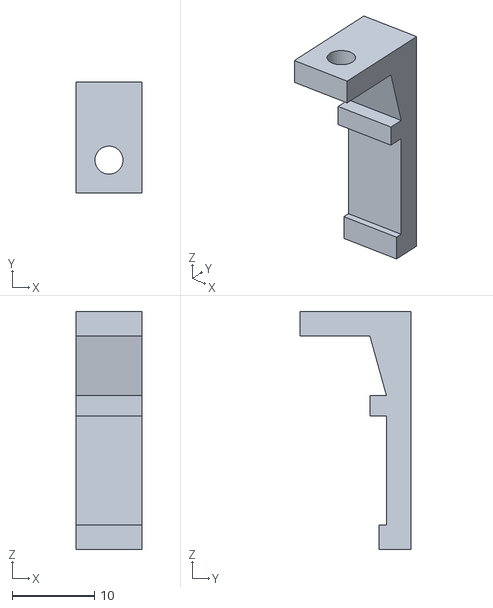
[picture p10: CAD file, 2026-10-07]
arm/ROS2/src/arm_asset/meshes/Left_Outer_Loose_C_Guide_Addon.stl
8.00 x 13.5 x 28.9

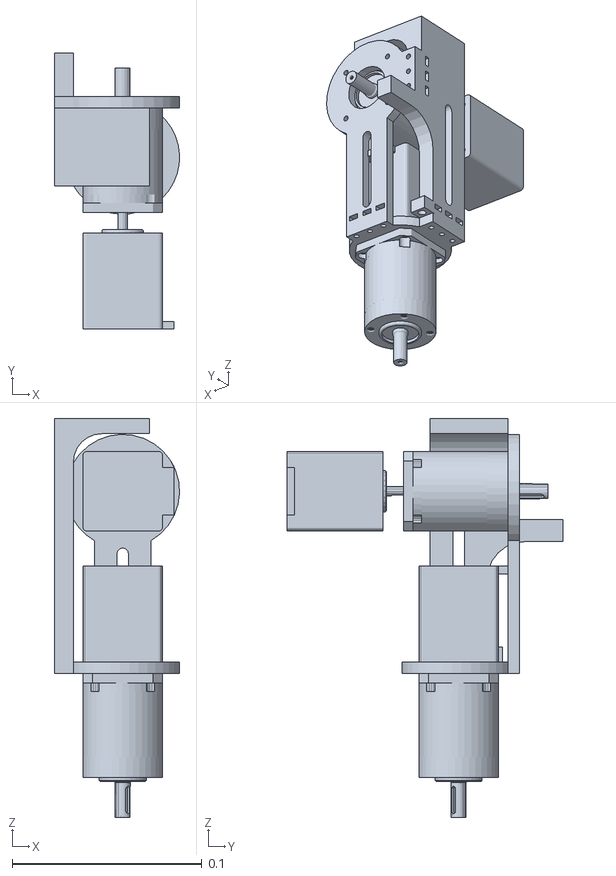
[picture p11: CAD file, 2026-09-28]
arm/ROS2/src/arm_asset/urdf/j1_Link.STL
0.066 x 0.146 x 0.21

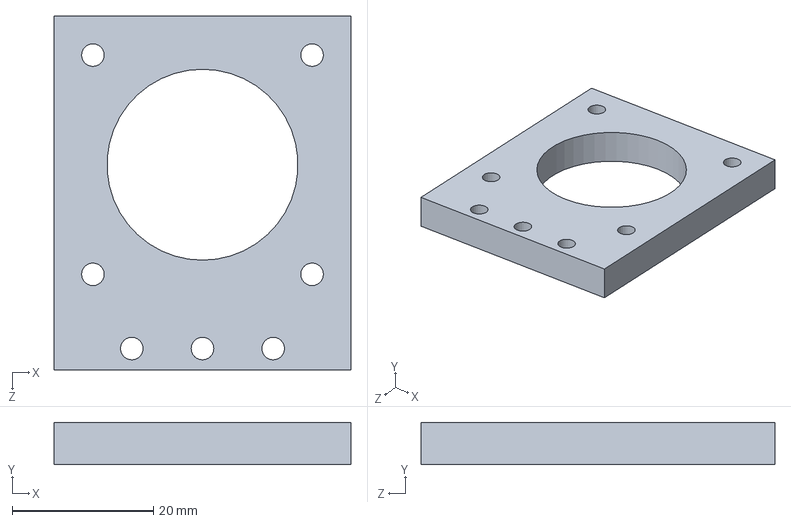
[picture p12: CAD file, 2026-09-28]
model/3D/sw/j3_4.SLDPRT
42.0 x 6.00 x 50.0 mm

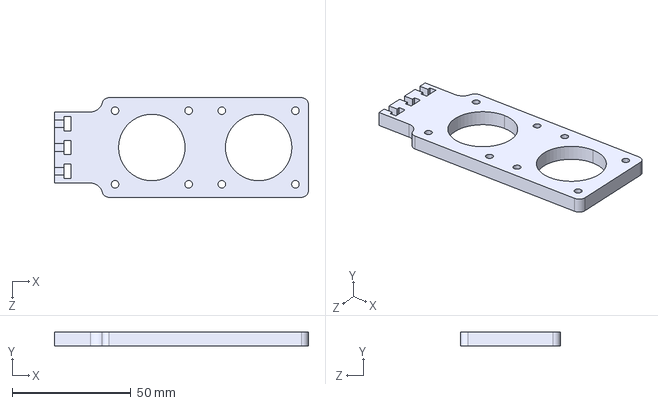
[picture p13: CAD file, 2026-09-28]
model/3D/加工/cnc/j4_2.STEP
107.0 x 6.00 x 42.0 mm

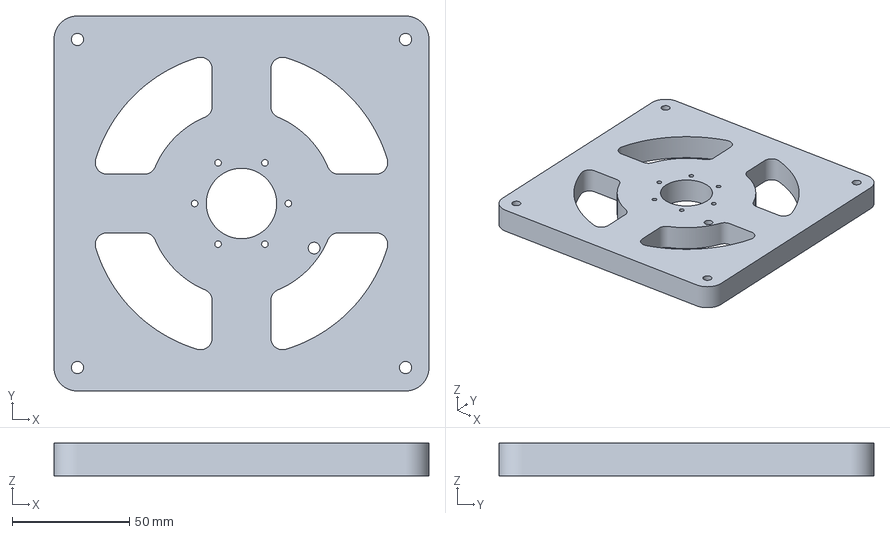
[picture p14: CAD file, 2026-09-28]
model/3D/加工/打印件/base_PETG透明_P1S.3mf
160.0 x 160.0 x 14.0 mm

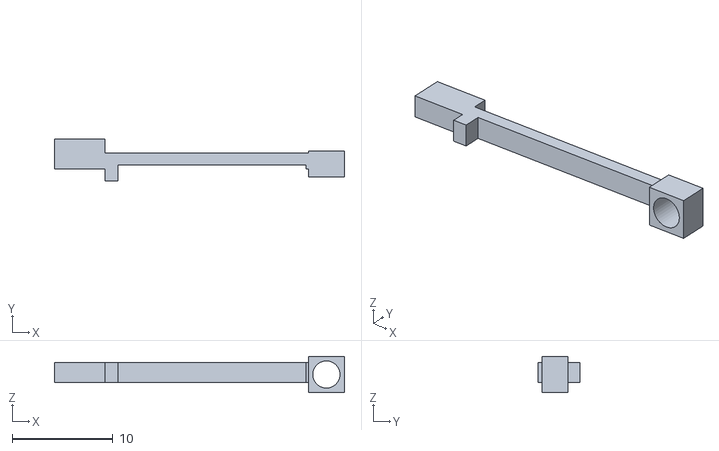
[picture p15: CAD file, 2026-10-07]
arm/ROS2/src/arm_asset/meshes/Quick_Latch.stl
28.8 x 4.20 x 3.60

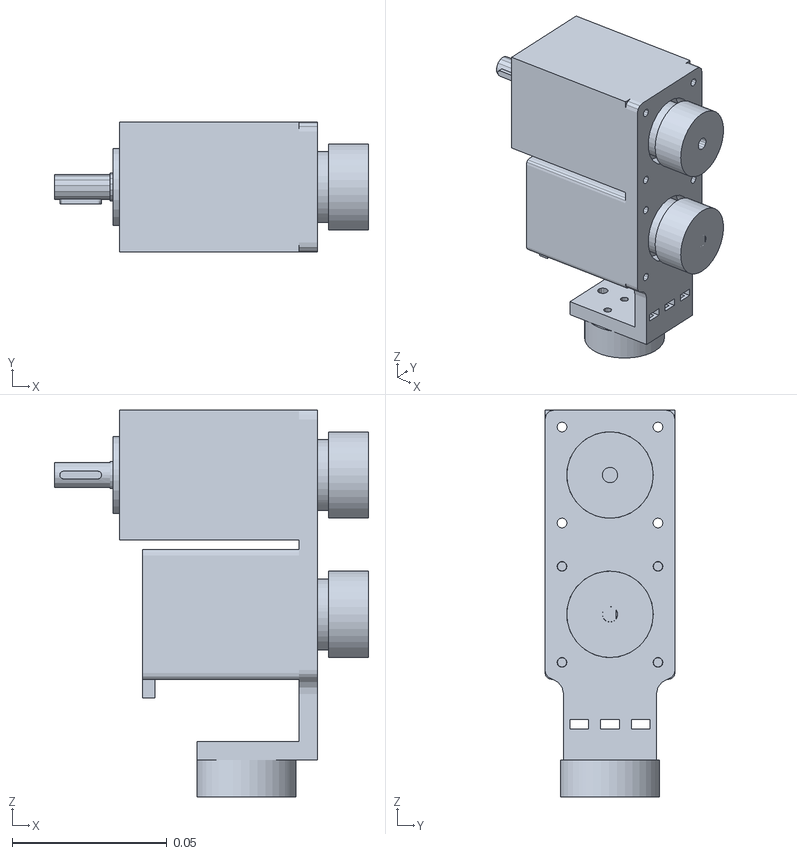
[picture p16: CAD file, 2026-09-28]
arm/ROS2/src/arm_asset/urdf/j4_Link.STL
0.102 x 0.042 x 0.125

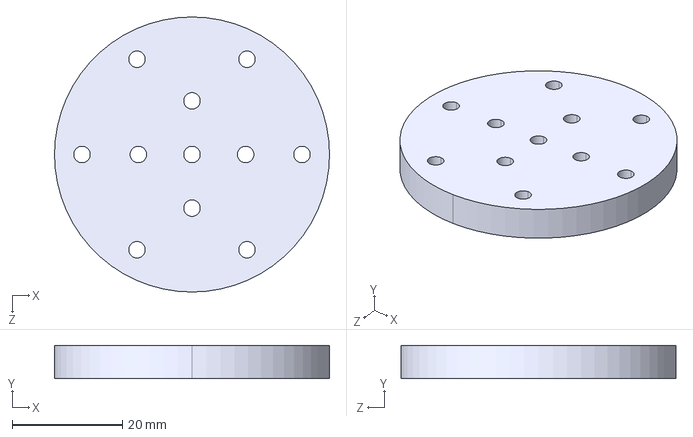
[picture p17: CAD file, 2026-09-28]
model/3D/加工/cnc/Waist.STEP
50.0 x 6.00 x 50.0 mm

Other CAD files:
model/3D/sw/ZDT_X42_L40Motor.SLDASM
model/3D/sw/PYF42-L2.SLDASM
model/3D/sw/装配体16.SLDASM
model/RL/src/model/meshes/Right_Finger.stl
arm/ROS2/src/arm_asset/meshes/Camera_Fusion.stl
arm/ROS2/src/arm_asset/meshes/Gripper_Base.stl
arm/ROS2/src/arm_asset/meshes/Left_Rack_Slider.stl
arm/ROS2/src/arm_asset/meshes/Motor_Driver_Module.stl
arm/ROS2/src/arm_asset/meshes/Motor_Mount_Frame.stl
arm/ROS2/src/arm_asset/meshes/Pinion_Retainer.stl
arm/ROS2/src/arm_asset/meshes/Replaceable_Hub_Insert.stl
arm/ROS2/src/arm_asset/meshes/Right_Finger.stl
arm/ROS2/src/arm_asset/meshes/Right_Outer_Loose_C_Guide_Addon.stl
arm/ROS2/src/arm_asset/meshes/Right_Rack_Slider.stl
arm/ROS2/src/arm_asset/meshes/Wrist_Flange.stl
arm/ROS2/src/arm_asset/meshes/j2_Link.STL
arm/ROS2/src/arm_asset/meshes/j3_Link.STL
arm/ROS2/src/arm_asset/meshes/j5_Link.STL
arm/ROS2/src/arm_asset/meshes/j6_Link.STL
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

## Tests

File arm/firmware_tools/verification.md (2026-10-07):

# 2026-10-08 仓库更新验证

本次更新 STM32、ESP32 与 REV6 最新双相机仿真。safe、code、三模型训练归档及历史 PCB 文件未修改。

| 项目 | 本次结果 | 边界 |
| --- | --- | --- |
| STM32F407VG 重新构建 | 成功，FLASH 24,940 B、RAM 6,464 B | GCC 15.3 工具链；保留 HAL 未使用参数及 nosys 链接警告 |
| ESP32 重新构建 | 成功，应用 1,710,674 B，全局 RAM 72,524 B | esp32 core 3.3.11，huge_app 3 MB；临时随机测试密钥，构建产物不发布 |
| 固件六组回归 | 全部通过，ASan/UBSan | 协议、应用、夹爪链路、CAN、权限/租约与轨迹；无硬件访问 |
| REV6 基础及任务场景 | 加载、两路渲染、各 100 步数值烟测通过 | MuJoCo 3.13.0；不等于任务成功率或碰撞验收 |
| 相机配置 | 前置 48°，腕部 45.2°；640×360 全视野补边至 256/512 方图 | 实拍人工对齐候选，尚未完成光学校准 |
| 模型来源 | 与来源 XML 语义一致，仅序列化与资源路径变更 | ROS MuJoCo 使用同一资源；历史 URDF 单独保留 |
| ROS 2 | 静态资源与单项 MJCF 契约检查通过 | 未执行 ROS 2 构建和运行 |
| 烧录及实机 | 未执行 | 不改变设备上的现有固件 |

源码来源是 FinalIntegration v3.0。`source_manifest.json` 的 `sha256` 为原源文件 hash，`published_sha256` 为仓库文件 hash；唯一固件文本差异是 `can.c` 的行尾空白规范化。源工程的旧 README/manifest 保留为历史材料，以本记录为当前验证依据。

STM32 构建方法见 `arm/STM32/README.md`，ESP32 配置及构建见 `arm/ESP32/README.md`。macOS 联合回归：

```sh
bash arm/firmware_tools/test_firmware.sh
```

注意量程：真实夹爪 0–74.63 mm，模型 0–80 mm；适配、标定和真实闭环需独立完成。仓库未包含原设备的无线密钥、私有配置或构建二进制。

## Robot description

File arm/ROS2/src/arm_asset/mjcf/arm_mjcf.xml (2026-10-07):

<?xml version='1.0' encoding='utf-8'?>
<mujoco model="ARM_6DOF_REV6_GRIPPER_CAMERA">

  <compiler angle="radian" autolimits="true" />
  <option timestep="0.002" wind="0 0 0" gravity="0 0 -9.81" integrator="implicitfast" density="1.225" />

  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

  <worldbody>
    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
    <light directional="true" ambient=".3 .3 .3" pos="30 30 30" dir="0 -2 -1" diffuse=".5 .5 .5" specular=".5 .5 .5" />
    <camera name="this_camera" pos="0 0 1.5" euler="0 0 0" fovy="45" />

    <camera name="front_rgb" pos="0.3665 0.028999999999999998 0.355" quat="0.803690166 0.42973988 0.194077538 0.362959587" fovy="48" /><body name="measured_robot_mount" pos=".08 .08 0" quat=".7071067811865476 0 0 -.7071067811865476"><body name="base_link" pos="-.08 -.08 0">
      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

      <body name="j1_Link" pos=".08 .08 .039" euler="0 0 3.14">
        <inertial pos="-.00368331 -.0113205 .112329" quat=".989154 -.00110874 .0655151 .131455" mass=".427328" diaginertia=".000224635 .00022137 .000123951" />
        <joint name="j1_joint" axis="0 0 -1" range="-3.14 3.14" actuatorfrcrange="-20 20" />
        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

        <body name="j2_Link" pos="0 .052981 .153" euler="1.57 0 0">
          <inertial pos="-.075 0 .00549028" quat="-.0000679812 .707107 .0000679812 .707107" mass=".0496479" diaginertia=".0000910862 .0000874226 .00000441999" />
          <joint name="j2_joint" axis="0 0 1" range="-3.14 0" actuatorfrcrange="-20 20" />
          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

          <body name="j3_Link" pos="-.15 0 .018">
            <inertial pos="-.0260794 .0312427 .0488675" quat=".500214 .500144 .499864 .499778" mass=".398882" diaginertia=".000137387 .00013361 .000114207" />
            <joint name="j3_joint" axis="0 0 1" range="-3.14 3.14" actuatorfrcrange="-20 20" />
            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

            <body name="j4_Link" pos=".009 .059361 .035" euler="3.1416 1.57 0">
              <inertial pos="-.00396142 -.00000113151 .0774846" quat=".510716 .489054 .48905 .510711" mass=".24806" diaginertia=".0000987684 .0000858838 .0000782496" />
              <joint name="j4_joint" axis="0 0 -1" range="-3.14 3.14" actuatorfrcrange="-20 20" />
              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

              <body name="j5_Link" pos="-.05 0 .104" euler="-1.57 1.57 -1.5708">
                <inertial pos=".0578983 .000000275448 .033873" quat=".621413 .338418 .339189 .619895" mass=".147033" diaginertia=".000119812 .000118284 .0000398727" />
                <joint name="j5_joint" axis="0 0 -1" range="-1.57 1.57" actuatorfrcrange="-20 20" />
                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

                <body name="j6_Link" pos=".1025 0 .05" euler="0 -1.5708 0">
                  <joint name="j6_joint" axis="0 0 -1" range="-3.14 3.14" actuatorfrcrange="-20 20" />

                  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


                  <body name="gripper_base" pos="0 0 -.0465" euler="3.141592653589793 0 0">
                    <inertial pos="0 .001 -.0035" mass=".141495" diaginertia=".00012913777 .000273981485 .000194744285" />


                    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


                    <body name="wrist_camera_body" pos=".018 -.068636332678 .005" quat="0 0 .138374145504 .990380025978">
                      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

                      <camera name="wrist_camera" pos=".018 -.018 .032" quat="0 0 1 0" fovy="45.2" />
                    </body>


                    <body name="ee_center_body" pos="0 0 .0697">
                      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
                    </body>

                    <body name="left_gripper_group">
                      <joint name="left_slide" type="slide" axis="1 0 0" range="-.04 0" damping="2" armature=".001" />
                      <inertial pos=".018 .00775 .0597499981" mass=".01303" diaginertia=".00000580210667 .00000945457854 .00000638931479" />
                      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
                    </body>

                    <body name="right_gripper_group">
                      <joint name="right_slide" type="slide" axis="1 0 0" range="0 .04" damping="2" armature=".001" />
                      <inertial pos="-.018 -.00775 .0597499981" mass=".01324" diaginertia=".00000589561721 .00000960695471 .00000649228917" />
                      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
                    </body>
                  </body>
                </body>
              </body>
            </body>
          </body>
        </body>
      </body>
    </body>
  </body>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</worldbody>

  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

  <tendon>
    <fixed name="gripper_opening">
      <joint joint="left_slide" coef="-1" />
      <joint joint="right_slide" coef="1" />
    </fixed>
  </tendon>

  <equality>
    <joint name="one_logical_gripper_dof" joint1="left_slide" joint2="right_slide" polycoef="0 -1 0 0 0" solref=".002 1" />
  </equality>

  <actuator>

    <position name="j1_ctrl" joint="j1_joint" kp="100" kv="10" ctrlrange="-3.14 3.14" forcerange="-20 20" />
    <position name="j2_ctrl" joint="j2_joint" kp="100" kv="10" ctrlrange="-3.14 0" forcerange="-20 20" />
    <position name="j3_ctrl" joint="j3_joint" kp="100" kv="10" ctrlrange="-3.14 3.14" forcerange="-20 20" />
    <position name="j4_ctrl" joint="j4_joint" kp="100" kv="10" ctrlrange="-3.14 3.14" forcerange="-20 20" />
    <position name="j5_ctrl" joint="j5_joint" kp="100" kv="10" ctrlrange="-2.2 2.2" forcerange="-20 20" />
    <position name="j6_ctrl" joint="j6_joint" kp="100" kv="10" ctrlrange="-3.14 3.14" forcerange="-20 20" />

    <position name="g" tendon="gripper_opening" kp="200" kv="5" ctrlrange="0 .08" forcerange="-10 10" />
  </actuator>

  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
</mujoco>

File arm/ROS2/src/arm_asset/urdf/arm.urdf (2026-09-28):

<?xml version="1.0" encoding="utf-8"?>
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
<robot name="arm">
  <link name="base_link">
    <inertial>
      <origin xyz="0.0799692719206064 0.00742234284803182 -0.0800188563158317" rpy="0 0 0" />
      <mass value="0.277082229693331" />
      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
    </inertial>
    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
  </link>
  <link name="j1_Link">
    <inertial>
      <origin xyz="-0.0036833069379518 -0.0113204704983923 0.112329221759019" rpy="0 0 0" />
      <mass value="0.427328177167994" />
      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
    </inertial>
    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
  </link>
  <joint name="j1_joint" type="revolute">
    <origin xyz="0.08 0.08 0.039" rpy="0 0 3.1416" />
    <parent link="base_link" />
    <child link="j1_Link" />
    <axis xyz="0 0 -1" />
    <limit lower="-3.14" upper="3.14" effort="20" velocity="10" />
  </joint>
  <link name="j2_Link">
    <inertial>
      <origin xyz="-0.075 8.32667268468867E-17 0.00549028411063959" rpy="0 0 0" />
      <mass value="0.049647885023324" />
      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
    </inertial>
    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
  </link>
  <joint name="j2_joint" type="revolute">
    <origin xyz="0 0.052981 0.153" rpy="1.5708 0 0" />
    <parent link="j1_Link" />
    <child link="j2_Link" />
    <axis xyz="0 0 1" />
    <limit lower="-3.14" upper="0" effort="20" velocity="10" />
  </joint>
  <link name="j3_Link">
    <inertial>
      <origin xyz="-0.026079401748195 0.031242688932016 0.0488675348398723" rpy="0 0 0" />
      <mass value="0.398881695490466" />
      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
    </inertial>
    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
  </link>
  <joint name="j3_joint" type="revolute">
    <origin xyz="-0.15 0 0.018" rpy="0 0 0" />
    <parent link="j2_Link" />
    <child link="j3_Link" />
    <axis xyz="0 0 1" />
    <limit lower="-3.14" upper="3.14" effort="20" velocity="10" />
  </joint>
  <link name="j4_Link">
    <inertial>
      <origin xyz="-0.00396142255227991 -1.13150731007039E-06 0.0774846361265533" rpy="0 0 0" />
      <mass value="0.24806031273061" />
      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
    </inertial>
    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
  </link>
  <joint name="j4_joint" type="revolute">
    <origin xyz="0.009 0.059361 0.035" rpy="0 -1.5708 0" />
    <parent link="j3_Link" />
    <child link="j4_Link" />
    <axis xyz="0 0 1" />
    <limit lower="-3.14" upper="3.14" effort="20" velocity="10" />
  </joint>
  <link name="j5_Link">
    <inertial>
      <origin xyz="0.0578982628392957 2.75447619713098E-07 0.0338729548732184" rpy="0 0 0" />
      <mass value="0.147033399849657" />
      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
    </inertial>
    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
  </link>
  <joint name="j5_joint" type="revolute">
    <origin xyz="-0.05 0 -0.104" rpy="0 1.5708 0" />
    <parent link="j4_Link" />
    <child link="j5_Link" />
    <axis xyz="0 0 -1" />
    <limit lower="-2.2" upper="2.2" effort="20" velocity="10" />
  </joint>
  <link name="j6_Link">
    <inertial>
      <origin xyz="-1.31949620674199E-09 -4.83060440537031E-08 -0.00986296292298143" rpy="0 0 0" />
      <mass value="0.0156026251336038" />
      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
    </inertial>
    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
  </link>
  <joint name="j6_joint" type="revolute">
    <origin xyz="0.1025 0 0.05" rpy="3.1416 1.5708 0" />
    <parent link="j5_Link" />
    <child link="j6_Link" />
    <axis xyz="0 0 -1" />
    <limit lower="-3.14" upper="3.14" effort="20" velocity="10" />
  </joint>
  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
<link name="ee_center_link">
  <inertial>
    <origin xyz="0 0 0" rpy="0 0 0"/>
    <mass value="0.01"/>
    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
  </inertial>
  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
</link>

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
<joint name="ee_fixed_joint" type="fixed">
  <origin xyz="0 0 -0.03" rpy="0 0 0"/>
  <parent link="j6_Link"/>
  <child link="ee_center_link"/>
</joint>
</robot>

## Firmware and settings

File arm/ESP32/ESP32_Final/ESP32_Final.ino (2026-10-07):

// GRIPPER_DENGFOC_P_FINAL_CAL459_ESP32 firmware version: v3.0-FINAL-INTERFACES
// Adapted from ToanTech/DengFOC_Lib (GPL-2.0).
// Source: https://github.com/ToanTech/DengFOC_Lib
#include <Arduino.h>
#include <driver/twai.h>
#include <esp_system.h>
#include "grip_can.h"
#include "grip_control.h"
#include "grip_motion.h"
#include "final_radio.h"
#include <Wire.h>
#include <Preferences.h>
#include <math.h>
#include <string.h>
HardwareSerial ArmLink(2);
constexpr int ARM_RX_PIN = 32;
constexpr int ARM_TX_PIN = 33;

// Drain telemetry only into available UART capacity; never wait for the wire.
class BufferedTelemetry : public Print {
 public:
  explicit BufferedTelemetry(HardwareSerial &serial) : port(serial) {}
  size_t write(uint8_t value) override {
    if (pending == sizeof(data)) { ++dropped; return 0; }
    data[tail] = value; tail = (tail + 1) % sizeof(data); ++pending;
    return 1;
  }
  void drain() {
    int capacity = port.availableForWrite();
    if (capacity <= 0 || pending == 0) return;
    size_t count = pending;
    if (count > static_cast<size_t>(capacity)) count = capacity;
    if (count > 64) count = 64;
    if (count > sizeof(data) - head) count = sizeof(data) - head;
    const size_t sent = port.write(data + head, count);
    head = (head + sent) % sizeof(data); pending -= sent;
  }
  size_t freeSpace() const { return sizeof(data) - pending; }
  uint32_t dropped = 0;
 private:
  HardwareSerial &port;
  uint8_t data[4096];
  size_t head = 0, tail = 0, pending = 0;
};
BufferedTelemetry UsbOutput(Serial), ArmOutput(ArmLink);
uint32_t controlMaxPeriodUs = 0;

// Mechanical-design monitor edition of the proven DengFOC pure-P branch.
// Boundaries are monitored and reported but never disable or latch the motor.
constexpr int PWM_A_PIN = 25;
constexpr int PWM_B_PIN = 13;
constexpr int PWM_C_PIN = 14;
constexpr int ENABLE_PIN = 27;
constexpr int AS5600_SDA_PIN = 22;
constexpr int AS5600_SCL_PIN = 21;

constexpr uint32_t PWM_FREQUENCY_HZ = 30000;
constexpr uint8_t PWM_RESOLUTION_BITS = 10;
constexpr uint8_t PWM_CHANNEL_A = 0;
constexpr uint8_t PWM_CHANNEL_B = 1;
constexpr uint8_t PWM_CHANNEL_C = 2;
constexpr uint32_t PWM_MAX_DUTY = (1UL << PWM_RESOLUTION_BITS) - 1UL;

constexpr int MOTOR_POLE_PAIRS = 7;
constexpr int SENSOR_DIRECTION = -1;
constexpr float BUS_VOLTAGE = 12.0f;
// Repeated 12 V SimpleFOC calibration after restoring the original phase order:
// zero electric angle repeatedly measured near 4.59 rad, direction remained -1.
constexpr float ZERO_ELECTRIC_ANGLE_RAD = 4.585066f;

// Exact DengFOC V0.1 example gain: Uq = 0.133 * position_error_degrees.
// The original 12 V example limits Uq to half the DC bus.
constexpr float POSITION_KP_V_PER_DEG = 0.133f;
constexpr float UQ_LIMIT_V = BUS_VOLTAGE * 0.5f;
constexpr float DEFAULT_TARGET_SLEW_RAD_S = 2.00f;
constexpr float MIN_TARGET_SLEW_RAD_S = 0.10f;
constexpr float MAX_TARGET_SLEW_RAD_S = 2.00f;

constexpr float PI_F = 3.14159265359f;
constexpr float TWO_PI_F = 6.28318530718f;
constexpr float PI_OVER_2_F = 1.57079632679f;
constexpr float PI_OVER_3_F = 1.04719755120f;
constexpr float SQRT3_F = 1.73205080757f;
constexpr float RAD_TO_DEG_F = 57.2957795131f;

constexpr float OPEN_ANGLE_RAD = -0.388097f;
constexpr float DEFAULT_CLOSED_ANGLE_RAD = -4.534447f;
constexpr float MIN_ALLOWED_CLOSED_ANGLE_RAD = -4.600000f;
constexpr float MAX_ALLOWED_CLOSED_ANGLE_RAD = -4.400000f;
constexpr float ABSOLUTE_CLOSED_HARD_RAD = -4.614447f;
constexpr float GAP_MM_PER_MOTOR_RAD = 18.0f;
constexpr float MIN_COMMAND_GAP_MM = 0.0f;

constexpr char CONFIG_NVS_NAMESPACE[] = "grip-deng-adj";
constexpr uint32_t CONFIG_NVS_MAGIC = 0x44475031UL;
constexpr uint32_t CONFIG_SCHEMA_VERSION = 2UL;

// Pure-P control retains a small static-friction position error. The measured
// Measured residuals were 0.069 rad at open and 0.0813 rad at closed. A 0.090
// rad mechanical-test arrival tolerance avoids false NO_PROGRESS reports. The
// P loop remains active and continues holding the exact target after arrival.
constexpr float TARGET_TOLERANCE_RAD = 0.090f;
constexpr unsigned long TARGET_STABLE_MS = 300;
constexpr float SOFT_LIMIT_TRIGGER_RAD = 0.010f;
constexpr float SOFT_LIMIT_RELEASE_RAD = 0.003f;
constexpr float OPEN_HARD_MARGIN_RAD = 0.300f;
constexpr unsigned long NO_PROGRESS_TIME_MS = 4000;
constexpr float PROGRESS_STEP_RAD = 0.010f;
constexpr uint8_t MAX_CONSECUTIVE_I2C_ERRORS = 3;

float clampValue(float value, float low, float high) {
  if (value < low) return low;
  if (value > high) return high;
  return value;
}

float moveTowards(float current, float target, float maximumStep) {
  return current + clampValue(target - current, -maximumStep, maximumStep);
}

float normalizeAngle(float angleRad) {
  float value = fmodf(angleRad, TWO_PI_F);
  return value >= 0.0f ? value : value + TWO_PI_F;
}

class DengAS5600 {
 public:
  bool begin(TwoWire* bus) {
    wire = bus;
    float firstAngle = 0.0f;
    if (!readMechanicalAngle(firstAngle)) return false;
    delayMicroseconds(10);
    anglePrevious = firstAngle;
    velocityAnglePrevious = firstAngle;
    angleTimestampUs = micros();
    velocityTimestampUs = angleTimestampUs;
    return true;
  }

  bool update() {
    float angle = 0.0f;
    if (!readMechanicalAngle(angle)) {
      if (consecutiveErrors < 255) ++consecutiveErrors;
      return false;
    }

    consecutiveErrors = 0;
    angleTimestampUs = micros();
    const float delta = angle - anglePrevious;
    if (fabsf(delta) > 0.8f * TWO_PI_F) {
      fullRotations += delta > 0.0f ? -1 : 1;
    }
    anglePrevious = angle;
    return true;
  }

  float mechanicalAngle() const {
    return anglePrevious;
  }

  float continuousAngle() const {
    return static_cast<float>(fullRotations) * TWO_PI_F + anglePrevious;
  }

  float velocity() {
    const uint32_t elapsedUs = angleTimestampUs - velocityTimestampUs;
    if (elapsedUs < 100) return lastVelocityRadS;

    const float dt = elapsedUs * 1.0e-6f;
    const float current = static_cast<float>(fullRotations) * TWO_PI_F
                        + anglePrevious;
    const float previous = static_cast<float>(velocityFullRotationsPrevious)
                         * TWO_PI_F + velocityAnglePrevious;
    lastVelocityRadS = (current - previous) / dt;

    // DengFOC updates these values even when angle delta is zero. Therefore a
    // stationary shaft reports 0 instead of retaining an old nonzero speed.
    velocityAnglePrevious = anglePrevious;
    velocityFullRotationsPrevious = fullRotations;
    velocityTimestampUs = angleTimestampUs;
    return lastVelocityRadS;
  }

  uint8_t errorCode() const { return lastWireError; }
  uint8_t errorCount() const { return consecutiveErrors; }

 private:
  bool readMechanicalAngle(float& angleRad) {
    wire->beginTransmission(0x36);
    wire->write(0x0C);
    // AS5600 register-pointer write and read are separate STOP-terminated transfers.
    // Avoid the combined write/read path implicated by the captured IDF panic.
    lastWireError = wire->endTransmission(true);
    if (lastWireError != 0) return false;

    const uint8_t received = wire->requestFrom(0x36, static_cast<uint8_t>(2));
    if (received != 2 || wire->available() < 2) {
      lastWireError = 0xFE;
      return false;
    }

    const uint8_t highByte = wire->read();
    const uint8_t lowByte = wire->read();
    const uint16_t raw =
      (static_cast<uint16_t>(highByte & 0x0F) << 8) | lowByte;
    angleRad = static_cast<float>(raw) * (TWO_PI_F / 4096.0f);
    return true;
  }

  TwoWire* wire = nullptr;
  float anglePrevious = 0.0f;
  uint32_t angleTimestampUs = 0;
  int32_t fullRotations = 0;
  float velocityAnglePrevious = 0.0f;
  uint32_t velocityTimestampUs = 0;
  int32_t velocityFullRotationsPrevious = 0;
  float lastVelocityRadS = 0.0f;
  uint8_t lastWireError = 0;
  uint8_t consecutiveErrors = 0;
};

DengAS5600 sensor;
Preferences preferences;

constexpr uint8_t BOUNDARY_NORMAL = 0;
constexpr uint8_t BOUNDARY_SOFT_OPEN = 1;
constexpr uint8_t BOUNDARY_SOFT_CLOSED = 2;
constexpr uint8_t BOUNDARY_HARD_OPEN = 3;
constexpr uint8_t BOUNDARY_HARD_CLOSED = 4;

bool driveEnabled = false;
bool motionActive = false;
bool targetReported = false;
uint8_t boundaryMonitorState = BOUNDARY_NORMAL;
float branchOffsetRad = 0.0f;
float closedLimitAngleRad = DEFAULT_CLOSED_ANGLE_RAD;
float targetSlewRateRadS = DEFAULT_TARGET_SLEW_RAD_S;
float targetAngleCanonicalRad = OPEN_ANGLE_RAD;
float trajectoryTargetAngleRad = OPEN_ANGLE_RAD;
float trajectoryVelocityRadS = 0.0f;
float currentAngleCanonicalRad = 0.0f;
float measuredVelocityRadS = 0.0f;
float filteredVelocityRadS = 0.0f;
float uqCommandV = 0.0f;
float lastProgressAngleRad = 0.0f;
uint32_t previousVelocityFilterUs = 0;
uint32_t previousTrajectoryUs = 0;
unsigned long lastProgressMs = 0;
unsigned long targetStableSinceMs = 0;

char serialLine[48];
uint8_t serialLength = 0;

float safeClosedAngle() {
  return closedLimitAngleRad;
}

float maximumGapMm() {
  return (OPEN_ANGLE_RAD - closedLimitAngleRad) * GAP_MM_PER_MOTOR_RAD;
}

float canonicalizeAngle(float angleRad) {
  const float midpoint = 0.5f * (OPEN_ANGLE_RAD + closedLimitAngleRad);
  while (angleRad - midpoint > PI_F) angleRad -= TWO_PI_F;
  while (angleRad - midpoint < -PI_F) angleRad += TWO_PI_F;
  return angleRad;
}

float canonicalAngleFromSensor() {
  return SENSOR_DIRECTION * sensor.continuousAngle() - branchOffsetRad;
}

float gapFromCanonicalAngle(float angleRad) {
  return clampValue(
    (angleRad - closedLimitAngleRad) * GAP_MM_PER_MOTOR_RAD,
    0.0f,
    maximumGapMm()
  );
}

float canonicalAngleFromGap(float gapMm) {
  const float safeGap = clampValue(
    gapMm,
    MIN_COMMAND_GAP_MM,
    maximumGapMm()
  );
  return closedLimitAngleRad + safeGap / GAP_MM_PER_MOTOR_RAD;
}

bool angleInsideHardEnvelope(float angleRad) {
  return angleRad >= ABSOLUTE_CLOSED_HARD_RAD
      && angleRad <= OPEN_ANGLE_RAD + OPEN_HARD_MARGIN_RAD;
}

float electricalAngle() {
  return normalizeAngle(
    static_cast<float>(SENSOR_DIRECTION * MOTOR_POLE_PAIRS)
      * sensor.mechanicalAngle()
    - ZERO_ELECTRIC_ANGLE_RAD
  );
}

void writeDuty(uint8_t channel, float duty) {
  const float safeDuty = clampValue(duty, 0.0f, 1.0f);
  ledcWriteChannel(
    channel,
    static_cast<uint32_t>(safeDuty * static_cast<float>(PWM_MAX_DUTY))
  );
}

void setNeutralPwm() {
  writeDuty(PWM_CHANNEL_A, 0.5f);
  writeDuty(PWM_CHANNEL_B, 0.5f);
  writeDuty(PWM_CHANNEL_C, 0.5f);
}

void setPwmOff() {
  writeDuty(PWM_CHANNEL_A, 0.0f);
  writeDuty(PWM_CHANNEL_B, 0.0f);
  writeDuty(PWM_CHANNEL_C, 0.0f);
}

void setTorqueSVPWM(float requestedUqV, float electricalAngleRad) {
  float uqV = clampValue(requestedUqV, -UQ_LIMIT_V, UQ_LIMIT_V);
  if (uqV < 0.0f) electricalAngleRad += PI_F;
  uqV = fabsf(uqV);

  const float angle = normalizeAngle(electricalAngleRad + PI_OVER_2_F);
  int sector = static_cast<int>(floorf(angle / PI_OVER_3_F)) + 1;
  sector = static_cast<int>(clampValue(sector, 1, 6));

  const float t1 = SQRT3_F
                 * sinf(sector * PI_OVER_3_F - angle)
                 * uqV / BUS_VOLTAGE;
  const float t2 = SQRT3_F
                 * sinf(angle - (sector - 1.0f) * PI_OVER_3_F)
                 * uqV / BUS_VOLTAGE;
  const float t0 = 1.0f - t1 - t2;

  float dutyA = 0.5f;
  float dutyB = 0.5f;
  float dutyC = 0.5f;
  switch (sector) {
    case 1:
      dutyA = t1 + t2 + t0 * 0.5f;
      dutyB = t2 + t0 * 0.5f;
      dutyC = t0 * 0.5f;
      break;
    case 2:
      dutyA = t1 + t0 * 0.5f;
      dutyB = t1 + t2 + t0 * 0.5f;
      dutyC = t0 * 0.5f;
      break;
    case 3:
      dutyA = t0 * 0.5f;
      dutyB = t1 + t2 + t0 * 0.5f;
      dutyC = t2 + t0 * 0.5f;
      break;
    case 4:
      dutyA = t0 * 0.5f;
      dutyB = t1 + t0 * 0.5f;
      dutyC = t1 + t2 + t0 * 0.5f;
      break;
    case 5:
      dutyA = t2 + t0 * 0.5f;
      dutyB = t0 * 0.5f;
      dutyC = t1 + t2 + t0 * 0.5f;
      break;
    case 6:
      dutyA = t1 + t2 + t0 * 0.5f;
      dutyB = t0 * 0.5f;
      dutyC = t1 + t0 * 0.5f;
      break;
  }

  writeDuty(PWM_CHANNEL_A, dutyA);
  writeDuty(PWM_CHANNEL_B, dutyB);
  writeDuty(PWM_CHANNEL_C, dutyC);
}

bool initializePwm() {
  pinMode(ENABLE_PIN, OUTPUT);
  digitalWrite(ENABLE_PIN, LOW);
  const bool aOk = ledcAttachChannel(
    PWM_A_PIN, PWM_FREQUENCY_HZ, PWM_RESOLUTION_BITS, PWM_CHANNEL_A);
  const bool bOk = ledcAttachChannel(
    PWM_B_PIN, PWM_FREQUENCY_HZ, PWM_RESOLUTION_BITS, PWM_CHANNEL_B);
  const bool cOk = ledcAttachChannel(
    PWM_C_PIN, PWM_FREQUENCY_HZ, PWM_RESOLUTION_BITS, PWM_CHANNEL_C);
  setPwmOff();
  return aOk && bOk && cOk;
}

bool saveConfiguration() {
  if (!preferences.begin(CONFIG_NVS_NAMESPACE, false)) return false;
  preferences.clear();
  const bool ok = preferences.putUInt("magic", CONFIG_NVS_MAGIC) > 0
               && preferences.putUInt("schema", CONFIG_SCHEMA_VERSION) > 0
               && preferences.putFloat("closed", closedLimitAngleRad) > 0
               && preferences.putFloat("slew", targetSlewRateRadS) > 0;
  preferences.end();
  return ok;
}

void loadConfiguration() {
  if (!preferences.begin(CONFIG_NVS_NAMESPACE, true)) return;
  const uint32_t magic = preferences.getUInt("magic", 0);
  const uint32_t schema = preferences.getUInt("schema", 0);
  const float savedClosed =
    preferences.getFloat("closed", DEFAULT_CLOSED_ANGLE_RAD);
  const float savedSlew =
    preferences.getFloat("slew", DEFAULT_TARGET_SLEW_RAD_S);
  preferences.end();

  const bool validExistingConfig = magic == CONFIG_NVS_MAGIC;
  if (validExistingConfig
      && isfinite(savedClosed)
      && savedClosed >= MIN_ALLOWED_CLOSED_ANGLE_RAD
      && savedClosed <= MAX_ALLOWED_CLOSED_ANGLE_RAD) {
    closedLimitAngleRad = savedClosed;
  }
  if (validExistingConfig
      && schema >= CONFIG_SCHEMA_VERSION
      && isfinite(savedSlew)
      && savedSlew >= MIN_TARGET_SLEW_RAD_S
      && savedSlew <= MAX_TARGET_SLEW_RAD_S) {
    targetSlewRateRadS = savedSlew;
  }

  // v2.1.1 migration: keep the calibrated mechanical closed boundary but
  // replace a legacy saved speed with the new R2 default exactly once.
  if (validExistingConfig && schema < CONFIG_SCHEMA_VERSION) {
    targetSlewRateRadS = DEFAULT_TARGET_SLEW_RAD_S;
    UsbOutput.println(saveConfiguration()
      ? "CONFIG_MIGRATED_DEFAULT_R2"
      : "ERR_CONFIG_MIGRATION_DEFAULT_R2");
  }
}

bool applyClosedBoundary(float requestedAngleRad) {
  if (driveEnabled) {
    UsbOutput.println("ERR_DISABLE_DRIVE_BEFORE_SETTING_CLOSED_BOUNDARY");
    return false;
  }
  if (!isfinite(requestedAngleRad)
      || requestedAngleRad < MIN_ALLOWED_CLOSED_ANGLE_RAD
      || requestedAngleRad > MAX_ALLOWED_CLOSED_ANGLE_RAD) {
    UsbOutput.print("ERR_CLOSED_BOUNDARY_RANGE allowed=");
    UsbOutput.print(MIN_ALLOWED_CLOSED_ANGLE_RAD, 6);
    UsbOutput.print("..");
    UsbOutput.println(MAX_ALLOWED_CLOSED_ANGLE_RAD, 6);
    return false;
  }

  closedLimitAngleRad = requestedAngleRad;
  targetAngleCanonicalRad = clampValue(
    targetAngleCanonicalRad,
    closedLimitAngleRad,
    OPEN_ANGLE_RAD
  );
  trajectoryTargetAngleRad = clampValue(
    trajectoryTargetAngleRad,
    closedLimitAngleRad,
    OPEN_ANGLE_RAD
  );
  UsbOutput.print(saveConfiguration()
    ? "CLOSED_BOUNDARY_SAVED angle_rad="
    : "ERR_CONFIG_SAVE closed_angle_rad=");
  UsbOutput.println(closedLimitAngleRad, 6);
  return true;
}

void setClosedBoundary(float requestedAngleRad) {
  applyClosedBoundary(requestedAngleRad);
}

void captureClosedBoundary() {
  applyClosedBoundary(currentAngleCanonicalRad);
}

void setTargetSlewRate(float requestedRateRadS) {
  if (!isfinite(requestedRateRadS)
      || requestedRateRadS < MIN_TARGET_SLEW_RAD_S
      || requestedRateRadS > MAX_TARGET_SLEW_RAD_S) {
    UsbOutput.print("ERR_SLEW_RANGE allowed=");
    UsbOutput.print(MIN_TARGET_SLEW_RAD_S, 2);
    UsbOutput.print("..");
    UsbOutput.println(MAX_TARGET_SLEW_RAD_S, 2);
    return;
  }

  targetSlewRateRadS = requestedRateRadS;
  UsbOutput.print(saveConfiguration()
    ? "TARGET_SLEW_SAVED rad_s="
    : "ERR_CONFIG_SAVE slew_rad_s=");
  UsbOutput.println(targetSlewRateRadS, 2);
}

void disableDrive(const char* reason) {
  digitalWrite(ENABLE_PIN, LOW);
  setPwmOff();
  driveEnabled = false;
  motionActive = false;
  uqCommandV = 0.0f;
  UsbOutput.print("DRIVE_DISABLED reason=");
  UsbOutput.println(reason);
}

void enableDriveAtCurrentPosition() {
  targetAngleCanonicalRad = clampValue(
    currentAngleCanonicalRad,
    safeClosedAngle(),
    OPEN_ANGLE_RAD
  );
  trajectoryTargetAngleRad = targetAngleCanonicalRad;
  trajectoryVelocityRadS = 0.0f;
  previousTrajectoryUs = micros();
  uqCommandV = 0.0f;
  setNeutralPwm();
  digitalWrite(ENABLE_PIN, HIGH);
  driveEnabled = true;
  motionActive = false;
  targetReported = false;
  targetStableSinceMs = 0;
  UsbOutput.print("DRIVE_ENABLED_TARGET_LOCKED angle_rad=");
  UsbOutput.println(targetAngleCanonicalRad, 6);
}

void startMoveToCanonicalAngle(float requestedTargetRad, const char* label) {
  if (!driveEnabled) {
    UsbOutput.println("ERR_DRIVE_DISABLED send E1 first");
    return;
  }

  targetAngleCanonicalRad = clampValue(
    requestedTargetRad,
    safeClosedAngle(),
    OPEN_ANGLE_RAD
  );
  // Preserve the running trajectory and velocity when the hand changes target.
  motionActive = true;
  targetReported = false;
  targetStableSinceMs = 0;
  lastProgressAngleRad = currentAngleCanonicalRad;
  lastProgressMs = millis();

  UsbOutput.print("MOVE_START target=");
  UsbOutput.print(label);
  UsbOutput.print(" target_angle_rad=");
  UsbOutput.print(targetAngleCanonicalRad, 6);
  UsbOutput.print(" target_gap_mm=");
  UsbOutput.println(gapFromCanonicalAngle(targetAngleCanonicalRad), 2);
}

void commandGapMm(float requestedGapMm) {
  const float safeGap = clampValue(
    requestedGapMm,
    MIN_COMMAND_GAP_MM,
    maximumGapMm()
  );
  if (safeGap != requestedGapMm) {
    UsbOutput.print("GAP_CLAMPED requested_mm=");
    UsbOutput.print(requestedGapMm, 2);
    UsbOutput.print(" applied_mm=");
    UsbOutput.println(safeGap, 2);
  }
  startMoveToCanonicalAngle(canonicalAngleFromGap(safeGap), "GAP");
}

void updateVelocityTelemetry() {
  const uint32_t nowUs = micros();
  const uint32_t elapsedUs = nowUs - previousVelocityFilterUs;
  if (elapsedUs < 5000) return;

  const float dt = elapsedUs * 1.0e-6f;
  measuredVelocityRadS = SENSOR_DIRECTION * sensor.velocity();
  const float filterAlpha = dt / (0.030f + dt);
  filteredVelocityRadS +=
    filterAlpha * (measuredVelocityRadS - filteredVelocityRadS);
  if (fabsf(filteredVelocityRadS) < 0.003f
      && fabsf(measuredVelocityRadS) < 0.003f) {
    filteredVelocityRadS = 0.0f;
  }
  previousVelocityFilterUs = nowUs;
}

const char* boundaryMonitorStateName(uint8_t state) {
  switch (state) {
    case BOUNDARY_NORMAL: return "NORMAL";
    case BOUNDARY_SOFT_OPEN: return "SOFT_OPEN";
    case BOUNDARY_SOFT_CLOSED: return "SOFT_CLOSED";
    case BOUNDARY_HARD_OPEN: return "HARD_OPEN";
    case BOUNDARY_HARD_CLOSED: return "HARD_CLOSED";
  }
  return "UNKNOWN";
}

uint8_t detectBoundaryMonitorState() {
  if (currentAngleCanonicalRad > OPEN_ANGLE_RAD + OPEN_HARD_MARGIN_RAD) {
    return BOUNDARY_HARD_OPEN;
  }
  if (currentAngleCanonicalRad < ABSOLUTE_CLOSED_HARD_RAD) {
    return BOUNDARY_HARD_CLOSED;
  }
  const float openThreshold = boundaryMonitorState == BOUNDARY_SOFT_OPEN
    ? OPEN_ANGLE_RAD - SOFT_LIMIT_RELEASE_RAD
    : OPEN_ANGLE_RAD + SOFT_LIMIT_TRIGGER_RAD;
  const float closedThreshold = boundaryMonitorState == BOUNDARY_SOFT_CLOSED
    ? closedLimitAngleRad + SOFT_LIMIT_RELEASE_RAD
    : closedLimitAngleRad - SOFT_LIMIT_TRIGGER_RAD;
  if (currentAngleCanonicalRad > openThreshold) {
    return BOUNDARY_SOFT_OPEN;
  }
  if (currentAngleCanonicalRad < closedThreshold) {
    return BOUNDARY_SOFT_CLOSED;
  }
  return BOUNDARY_NORMAL;
}

void updateBoundaryMonitor() {
  const uint8_t detected = detectBoundaryMonitorState();
  if (detected == boundaryMonitorState) return;
  boundaryMonitorState = detected;
  UsbOutput.print("BOUNDARY_MONITOR state=");
  UsbOutput.print(boundaryMonitorStateName(boundaryMonitorState));
  UsbOutput.print(" angle_rad=");
  UsbOutput.print(currentAngleCanonicalRad, 6);
  UsbOutput.println(" action=MONITOR_ONLY");
}
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
void loop() {
  UsbOutput.drain();
  ArmOutput.drain();
  readArmCommands();
  pollGripperCAN();
  pollFinalRadio();
  static uint32_t lastSensorPollUs = 0;
  const uint32_t nowSensorUs = micros();
  if (nowSensorUs - lastSensorPollUs < 2000U) {
    readSerialCommands();
    delayMicroseconds(100);
    return;
  }
  if (lastSensorPollUs != 0 && nowSensorUs - lastSensorPollUs > controlMaxPeriodUs)
    controlMaxPeriodUs = nowSensorUs - lastSensorPollUs;
  lastSensorPollUs = nowSensorUs;
  if (!sensor.update()) {
    if (sensor.errorCount() >= MAX_CONSECUTIVE_I2C_ERRORS && driveEnabled) {
      UsbOutput.print("FAULT_AS5600 code="); UsbOutput.print(sensor.errorCode());
      UsbOutput.print(" consecutive="); UsbOutput.println(sensor.errorCount());
      disableDrive("AS5600_I2C_FAULT");
    }
    readSerialCommands();
    return;
  }

  gripSensorMs = millis();
  currentAngleCanonicalRad = canonicalAngleFromSensor();
  updateVelocityTelemetry();
  updateBoundaryMonitor();

  // Mechanical monitor edition: every boundary state is telemetry-only.
  // The clamped target and pure-P restoring action remain active at all times.
  if (driveEnabled) {
    runDengPositionLoop();
    updateArrivalAndProgress();
  }

  readSerialCommands();
}

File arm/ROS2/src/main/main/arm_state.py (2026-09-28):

from copy import deepcopy
from datetime import datetime, timezone
import json
import math
import os
from pathlib import Path
import tempfile
import threading
import time

from ament_index_python.packages import get_package_share_directory, PackageNotFoundError
from geometry_msgs.msg import Point, PointStamped
import numpy as np
import rclpy
from rclpy.node import Node
from rclpy.qos import DurabilityPolicy, QoSProfile, ReliabilityPolicy
from sensor_msgs.msg import JointState
import serial
from std_msgs.msg import Bool, Float32, String


GOAL_TYPES = ('A', 'B', 'C', 'D')
ARM_FRAME_HEADER = ord('A')
ARM_FRAME_TAIL = ord('B')
K230_FRAME_HEADER = ord('E')
K230_FRAME_TAIL = ord('P')
CAPTURE_STATUS_TOPIC = '/arm_capture_status'
CAPTURE_TARGET_TIMEOUT_SECONDS = 2.0
SERIAL_BUFFER_LIMIT_BYTES = 256

# 统一串口帧协议（合并决策 Q1）：U,{OK},{p1..p6},{STOP},{PUMP},{SPD}*CHK\r\n
# 字段取 'MM' 表示本拍无操作；OK 为喂狗字段，必须按周期强发（不得被去重饿死）。
UNIFIED_FIELD_NOOP = 'MM'
UNIFIED_WATCHDOG_OK = 'OK'
UNIFIED_SEND_PERIOD_SECONDS = 0.5
PICK_COMMAND = 'CPQE'    # PUMP 字段：吸取
PLACE_COMMAND = 'PUT'    # PUMP 字段：放置（停止吸取）
STOP_COMMAND = 'CD'      # STOP 字段：急停
RECOVER_COMMAND = 'EF'   # STOP 字段：恢复运动

# K230 像素 -> 机械臂坐标备用仿射（mujoco_ws (5) 手眼参数）。
# 全文件唯一一套系数：is_goal_valid 校验与抓取发布路径共用 k230_pixel_goal_to_arm_point，
# 消除 WS710 校验/发布双系数 1cm 漂移。
K230_AFFINE_X = (-0.000300211, 0.000011308, 0.246757)
# 参考 Y 截距 0.450067，加 0.01 m 实机落点补偿。
K230_AFFINE_Y = (-0.000019886, -0.000271216, 0.470067)
GOAL_HEIGHT = 0.09

# 工作空间边界 + 粗界限第一道门（粗界限 0.38 与 ik_control workspace 上界对齐）
WORKSPACE_BOUNDS = {
    'x_min': -0.32,
    'x_max': 0.38,
    'y_min': -0.32,
    'y_max': 0.38,
    'z_min': 0.05,
    'z_max': 0.30,
}
ROUGH_XY_BOUND_MIN = -0.32
ROUGH_XY_BOUND_MAX = 0.38

# 抓放状态机时序（照抄 WS710 goal_pos_pub）
PICK_TRAVEL_SECONDS = 18.0
PICK_PUMP_SECONDS = 2.0
LIFT_TRAVEL_SECONDS = 5.0
MIDDLE_TRAVEL_SECONDS = 4.0
SECOND_MIDDLE_TRAVEL_SECONDS = 4.0
PLACE_PUMP_SECONDS = 6.0
LOOK_TRAVEL_SECONDS = 8.0
LIFT_J2_RADIANS = 0.5

# 关节空间路点（下位机原始编码值，队友标定）
LOOK_JOINT_POSITIONS = (383730, 515190, 635910, 970, 157790, 8489)
MIDDLE_JOINT_POSITIONS = (0, 452940, 330210, 10, 88010, 9986)
SECOND_MIDDLE_JOINT_POSITIONS = (0, 552940, 350210, 10, 68010, 9986)

# 开机观察位三步序列（取代旧 /control 首帧 init 三步，二者不得并存）
LOOK_SEQUENCE_DELAY_SECONDS = 8.0
LOOK_STEP1_WAIT_SECONDS = 5.0
LOOK_STEP2_WAIT_SECONDS = 2.0

# 与 AI 侧 local_safety_assistant/arm_rules.py 的 DEFAULT_ARM_RULE_DOCUMENT 保持一致；
# 该 JSON 通道由 07-09-migrate-json-commands-to-ros 任务负责最终下线。
DEFAULT_ARM_RULES = {
    'arm_capture': 'False',
    'arm_capture_goal': 'A',
    'arm_decelerate': '1.0',
    'arm_stop': 'False',
    'arm_recover': 'False',
    'arm_safety_distance': '0.4',
}
PERSONNEL_DISTANCE_RULE_ID = 'stop_on_person_intrusion'
DEFAULT_PERSONNEL_DISTANCE_M = float(DEFAULT_ARM_RULES['arm_safety_distance'])
DEFAULT_SAFETY_RULES_VERSION = 1
OWNER_QOS = QoSProfile(
    depth=1,
    durability=DurabilityPolicy.TRANSIENT_LOCAL,
    reliability=ReliabilityPolicy.RELIABLE,
)


def default_handeye_calibration_path():
    configured_path = os.environ.get('AI_OV_HANDEYE_CALIBRATION_FILE', '').strip()
    if configured_path:
        return Path(configured_path).expanduser()
    try:
        return (
            Path(get_package_share_directory('control'))
            / 'config'
            / 'handeye_xy.yaml'
        )
    except PackageNotFoundError:
        return (
            Path(__file__).resolve().parents[2]
            / 'control'
            / 'config'
            / 'handeye_xy.yaml'
        )


def reset_personnel_distance_rule(document, distance_m=DEFAULT_PERSONNEL_DISTANCE_M):
    if not isinstance(document, dict):
        raise ValueError('安全规则文档必须是 JSON 对象')

    version = document.get('version')
    if not isinstance(version, int) or isinstance(version, bool):
        raise ValueError("安全规则文档缺少整数 'version'")

    rules = document.get('rules')
    if not isinstance(rules, list):
        raise ValueError("安全规则文档缺少数组 'rules'")

    matching_indexes = []
    for index, rule in enumerate(rules):
        if not isinstance(rule, dict):
            raise ValueError(f'安全规则第 {index} 项必须是 JSON 对象')
        if rule.get('id') == PERSONNEL_DISTANCE_RULE_ID:
            matching_indexes.append(index)

    if len(matching_indexes) != 1:
        raise ValueError(
            f'安全规则必须且只能包含一条 {PERSONNEL_DISTANCE_RULE_ID!r} 规则')

    rule_index = matching_indexes[0]
    conditions = rules[rule_index].get('conditions')
    if not isinstance(conditions, dict):
        raise ValueError('人员安全距离规则缺少 conditions 对象')
    person_distance = conditions.get('person_distance_m')
    if not isinstance(person_distance, dict):
        raise ValueError('人员安全距离规则缺少 person_distance_m 对象')
    current_distance = person_distance.get('lt')
    if (
        not isinstance(current_distance, (int, float))
        or isinstance(current_distance, bool)
        or not math.isfinite(float(current_distance))
    ):
        raise ValueError('人员安全距离规则的 lt 必须是有限数值')

    if (
        float(current_distance) == float(distance_m)
        and version == DEFAULT_SAFETY_RULES_VERSION
    ):
        return document, False

    updated = deepcopy(document)
    updated['rules'][rule_index]['conditions']['person_distance_m']['lt'] = float(distance_m)
    updated['version'] = DEFAULT_SAFETY_RULES_VERSION
    return updated, True


def parse_numeric_frame(frame, header, tail, min_values):
    text = bytes(frame).decode('utf-8', errors='ignore').strip()
    if not text.startswith(header) or not text.endswith(tail):
        return None

    parts = text[1:-1].replace(',', ' ').split()
    if len(parts) < min_values:
        return None

    try:
        values = [float(part) for part in parts[:min_values]]
    except ValueError:
        return None
    if not all(math.isfinite(value) for value in values):
        return None
    return values


def parse_arm_joint_frame(frame):
    return parse_numeric_frame(frame, 'A', 'B', 6)


def parse_k230_goal_frame(frame):
    values = parse_numeric_frame(frame, 'E', 'P', 8)
    if values is None:
        return None
    return {
        goal_type: [values[index * 2], values[index * 2 + 1]]
        for index, goal_type in enumerate(GOAL_TYPES)
    }


def k230_pixel_goal_to_arm_point(pixel_goal, goal_height=GOAL_HEIGHT):
    # 像素目标 -> 机械臂坐标的唯一标定入口（校验与发布共用，杜绝双系数漂移）
    if len(pixel_goal) < 2:
        return None

    pixel_x = float(pixel_goal[0])
    pixel_y = float(pixel_goal[1])
    if not math.isfinite(pixel_x) or not math.isfinite(pixel_y):
        return None
    if pixel_x == 0.0 and pixel_y == 0.0:
        return None

    ax, ay, a0 = K230_AFFINE_X
    bx, by, b0 = K230_AFFINE_Y
    return (
        ax * pixel_x + ay * pixel_y + a0,
        bx * pixel_x + by * pixel_y + b0,
        goal_height,
    )
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

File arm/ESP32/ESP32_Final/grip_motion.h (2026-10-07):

#ifndef GRIP_MOTION_H
#define GRIP_MOTION_H
#include <math.h>
#define GM_ACCELERATION 1.5f
#define GM_MAX_SPEED (25.0f / 18.0f)
#define GM_END_MIN_SPEED 0.1f
#define GM_END_BAND_MM 10.0f
/* Bounds apply to the trajectory, not a certification of measured motor speed. */
static inline float gm_towards(float x,float y,float step) {
 return x<y?fminf(x+step,y):fmaxf(x-step,y);
}
static inline void gm_step(float *position,float *velocity,float target,float low,float high,float requested,float dt) {
 const float acceleration=GM_ACCELERATION,maximum=GM_MAX_SPEED,minimum=GM_END_MIN_SPEED;
 if(!(dt>0.0f)||dt>0.01f||!isfinite(target)||!isfinite(*position)||!isfinite(*velocity))return;
 target=fminf(high,fmaxf(low,target));
 const float distance=target-*position;
 const float endpoint_distance=fmaxf(0.0f,fminf(*position-low,high-*position));
 const float end_fraction=fminf(1.0f,endpoint_distance/(GM_END_BAND_MM/18.0f));
 const float endpoint_limit=minimum+(maximum-minimum)*end_fraction;
 const float limit=fminf(fmaxf(0.0f,requested),fminf(maximum,endpoint_limit));
 const float braking_limit=sqrtf(2.0f*acceleration*fabsf(distance));
 const float desired=(distance>=0.0f?1.0f:-1.0f)*fminf(limit,braking_limit);
 const float next=gm_towards(*velocity,desired,acceleration*dt);
 float advanced=*position+0.5f*(*velocity+next)*dt;
 *velocity=next;
 /* While reversing, deceleration may continue briefly in the old direction. */
 if(advanced<low){advanced=low;*velocity=0.0f;}
 if(advanced>high){advanced=high;*velocity=0.0f;}
 if(fabsf(distance)<0.0001f && fabsf(next)<acceleration*dt){advanced=target;*velocity=0.0f;}
 *position=advanced;
}
#endif

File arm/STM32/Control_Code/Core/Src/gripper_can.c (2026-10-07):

#include "gripper_can.h"
#include "grip_control.h"
#include "can.h"
#include "usart.h"
#include <stdio.h>
#include <string.h>
#include <limits.h>
static uint32_t sequence,command_sequence;
static unsigned retries,invalid,stale,timeouts;
static uint8_t state[GC_BYTES];
static void host(const char *s){(void)HAL_UART_Transmit(&huart1,(uint8_t *)s,(uint16_t)strlen(s),100U);}
static int receive(CAN_RxHeaderTypeDef *rx,uint8_t *data){return HAL_CAN_GetRxFifoFillLevel(&hcan2,CAN_RX_FIFO1)&&HAL_CAN_GetRxMessage(&hcan2,CAN_RX_FIFO1,rx,data)==HAL_OK;}
static int drain(void){CAN_RxHeaderTypeDef rx;uint8_t d[8];unsigned n;for(n=0;n<32U&&receive(&rx,d);++n){}return n<32U;}
static int tx_frame(uint32_t id,uint8_t *data,uint32_t *mailbox){CAN_TxHeaderTypeDef tx={0};tx.IDE=CAN_ID_EXT;tx.RTR=CAN_RTR_DATA;tx.ExtId=id;tx.DLC=8;return HAL_CAN_AddTxMessage(&hcan2,&tx,data,mailbox)==HAL_OK;}
static int fetch(void){
 uint8_t req[8],data[8];uint16_t mask=0;CAN_RxHeaderTypeDef rx;uint32_t seq=++sequence,mailbox,start;unsigned attempt;
 if(!seq)seq=++sequence;
 if(!drain()){host("GRIP_CAN_RX_BUSY feedback_invalid=1\r\n");return 0;}
 gc_request(req,seq);
 for(attempt=0;attempt<3U;++attempt){
  if(attempt)++retries;
  if(!tx_frame(GC_REQUEST_ID,req,&mailbox))continue;
  start=HAL_GetTick();
  while(HAL_GetTick()-start<100U){
   if(!receive(&rx,data))continue;
   if(rx.IDE!=CAN_ID_EXT||rx.RTR!=CAN_RTR_DATA||rx.DLC!=8||rx.ExtId<GC_REPLY_ID||rx.ExtId>=GC_REPLY_ID+GC_PARTS){++invalid;continue;}
   if(gc_get32(data)!=seq){++stale;continue;}
   unsigned part=(unsigned)(rx.ExtId-GC_REPLY_ID);memcpy(state+4U*part,data+4,4);mask|=(uint16_t)(1U<<part);
   if(mask!=((1U<<GC_PARTS)-1U))continue;
   if(!gc_valid(seq,state)){++invalid;mask=0;continue;}return 1;
  }
  (void)HAL_CAN_AbortTxRequest(&hcan2,mailbox);
 }
 ++timeouts;host("GRIP_CAN_TIMEOUT feedback_invalid=1 no automatic motion\r\n");return 0;
}
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

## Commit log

2026-09-28 Upload arm and model project files
    [PYF42-L2.SLDASM, Waist.SLDPRT, Waist.STEP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]
2026-10-07 Update paired STM32 ESP32 firmware and REV6 camera simulation
    [Camera_Fusion.stl, Gripper_Base.stl, Left_Finger.stl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]
2026-10-11 Archive stage-supervised v1 and v2 Transport research results
